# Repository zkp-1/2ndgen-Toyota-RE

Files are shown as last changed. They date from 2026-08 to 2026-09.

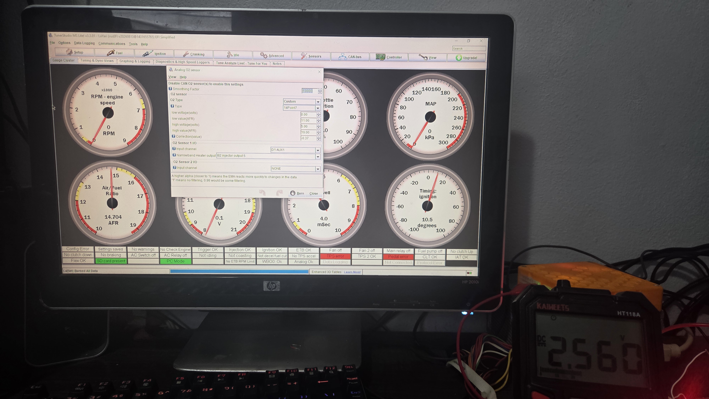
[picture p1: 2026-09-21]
AFR-Sensor/Testbench/20260920_163902.jpg

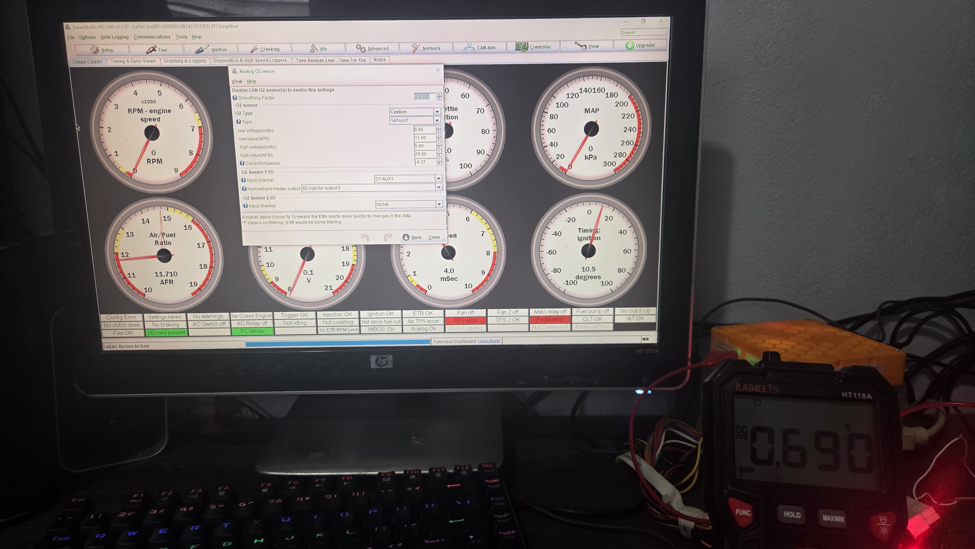
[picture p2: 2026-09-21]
AFR-Sensor/Testbench/20260920_163911.jpg

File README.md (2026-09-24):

# (1NZ-FE) Yaris Reverse Engineering
Reverse Engineering focused on the 1NZ-FE Platform for 2nd gen Yaris/Vitz.
My main focus is for this platform to be accesible in a plug and play fashion for the Rusefi Platform, although it could be done with other platforms if they can drive the ETB natively. I don't have a junker car or most parts to physically bench test, but I'll do my best to keep it updated as I make any progress on the project at all if any.

If you have anything that is useful to utilize the stock harness with a standalone ECU or pertinent info (like CANBUS chatter and labeled CANIDs) feel free to share it here, on any other repo, forum online or youtube video. Gatekeeping information just to possibly get a few bucks off from it rather than sharing it with everybody to access and analyze is honestly a waste of potential. These platforms are old, discontinued and not even popular at all. There honestly isn't a reason to share these things for the few people who like it other than abstaining from helping the platform stay alive.
# Useful links
- [Haltech 1NZ-FE Wiring Guide for their ECUs](https://support.haltech.com/portal/en/kb/articles/1nz-fe-engine). Has crank, cam, ETB and timing info.
# Disclaimers
This project is not affiliated with, endorsed by, or sponsored by Toyota. Toyota names, marks, vehicle model names, chassis codes, and engine codes are used only for identification and compatibility research.
# Continued
This project is licensed under the GNU General Public License v3.0 or later.

This project is intended for educational, research, motorsport, and off-road use only. Vehicle ECU, wiring, sensor, and engine-control modifications can cause engine damage, electrical damage, emissions noncompliance, unsafe vehicle behavior, personal injury, or death.

This project is not affiliated with, endorsed by, or sponsored by Toyota. Toyota names, marks, and vehicle identifiers are used only for compatibility and research identification.

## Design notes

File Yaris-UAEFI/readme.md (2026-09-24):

# Comments
Mostly untested. However tying MREL and IGSW do work (I have tried it). 

I've had mixed results with the ETB on the UAEFI. Sometimes it works, sometimes it doesn't. Am guessing it's a physical grounding issue on the harness adapter I have.

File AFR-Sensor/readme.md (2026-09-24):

# Recommendation: Use the 0-5V versions of the Projects

# Multisim folder

- Has the main 0-5V circuit. Mostly did the testing there. Voltage references are real and not ideal (Voltage dividers).
- It has a bunch of comments accounting for stuff like if there were a short circuit, component selection... etc.

# LTSpice folder

- Has both main and OEM style circuit. Does NOT have voltage dividers.
- Has the operation graphs (behavior at different currents).

# Testbench folder

- Custom iteration of the circuit (non-rail to rail op-amp with a pot voltage divider and an older design).
- Pertinent testing information.
- Power draw is <20mA using 12V and 5V. With a status led, it is <50mA.

# KiCAD
- Design block of the circuit.

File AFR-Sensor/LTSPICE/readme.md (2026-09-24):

For 3.3V circuit:

~4.50V: ~19AFR [2.5mA]

3.30V: 14.7AFR [0mA]

~2.35V: ~12AFR [-2mA]

(Using the Planar A/F Sensor Review data. The circuit isn't exactly 1:1 with the graph, since the graph isn't linear but somewhat exponential.)

For 2.5V circuit:

~5V: ~19AFR [0.8mA]

2.5V: 14.7AFR [0mA]

~0V: ~12AFR [-0.8mA]

(Note: Since the differential voltage changes here, the lean reading in reality might be less than 19AFR maybe).

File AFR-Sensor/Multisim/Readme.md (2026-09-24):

The multisim file has a lot of comments inside the design. I'll mention the important ones.
Op-amp: I utilzed the MCP6024 since it's a quad, rail-to-rail and can handle -40C thru 120C operation. If you change the op-amp for another one, make sure it is rail to rail, and that it has a good PSRR (power supply rejection ratio; which is how stable it'll behave if the power supply voltage varies) and CMRR (Common mode rejection ratio; which is external noise attenuation).
Shunt AND op-amp inverting and feedback resistance: Select resistors with low ppm (<100, less than <50 is even better). Power rating can be 1/8W or greater.
Emitter resistors:  Select 120ohm resistors of 1/2W capability for safety. It can handle 1/4W during a short circuit to ground, but it is slightly over 80% using 1/4W as a reference but less than 1/4W.
Capacitors: X7R should be good, with good voltage capacity (50V peak to start). Haven't investigated too much into it as of sept 23 2026.
Voltage dividers: They can be separated and each output buffered if desired.
--- If the circuit is to be tested physically ---
On the Shunt measurement rail, sink your desired current using I = Vrail/R (Sinking current means connecting a resistor to the rail, and the other terminal to ground). This simulates a shift to lean condition.
To simulate a rich condition shift, add any voltage (doesn't matter magnitude since the op-amp will force whatever the rail gets to Vrail) in series with the resistor, and this will inject/source current into the shunt, making the PNP sink the current. The equation remains: I = Vrail/R.
If using the 2.5V design, then Vrail = 2.5V. If using the Toyota style references, then Vrail = 3.3V.
Expected behavior:
Idle (no sourcing/sinking): V = Stoich (~2.5V default)
Fully lean (sinking 0.8mA): V = +5V
Fully rich (sourcing 0.8mA): V = 0V (may be millivolts, but it should be less than 500mV)
For more info or a schematic, lookup the testbench circuit I made alongside my results as a reference in the repo.

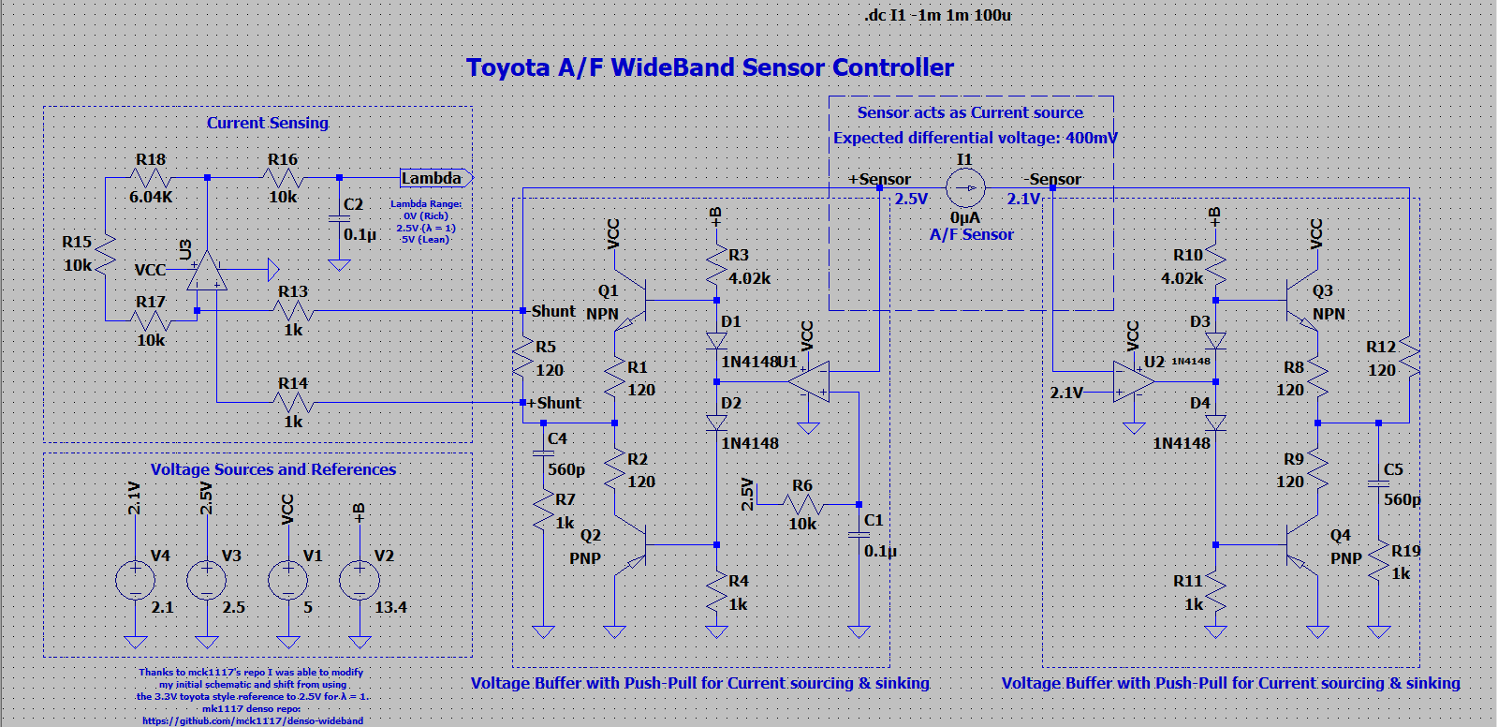
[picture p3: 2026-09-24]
AFR-Sensor/LTSPICE/Schematic.PNG

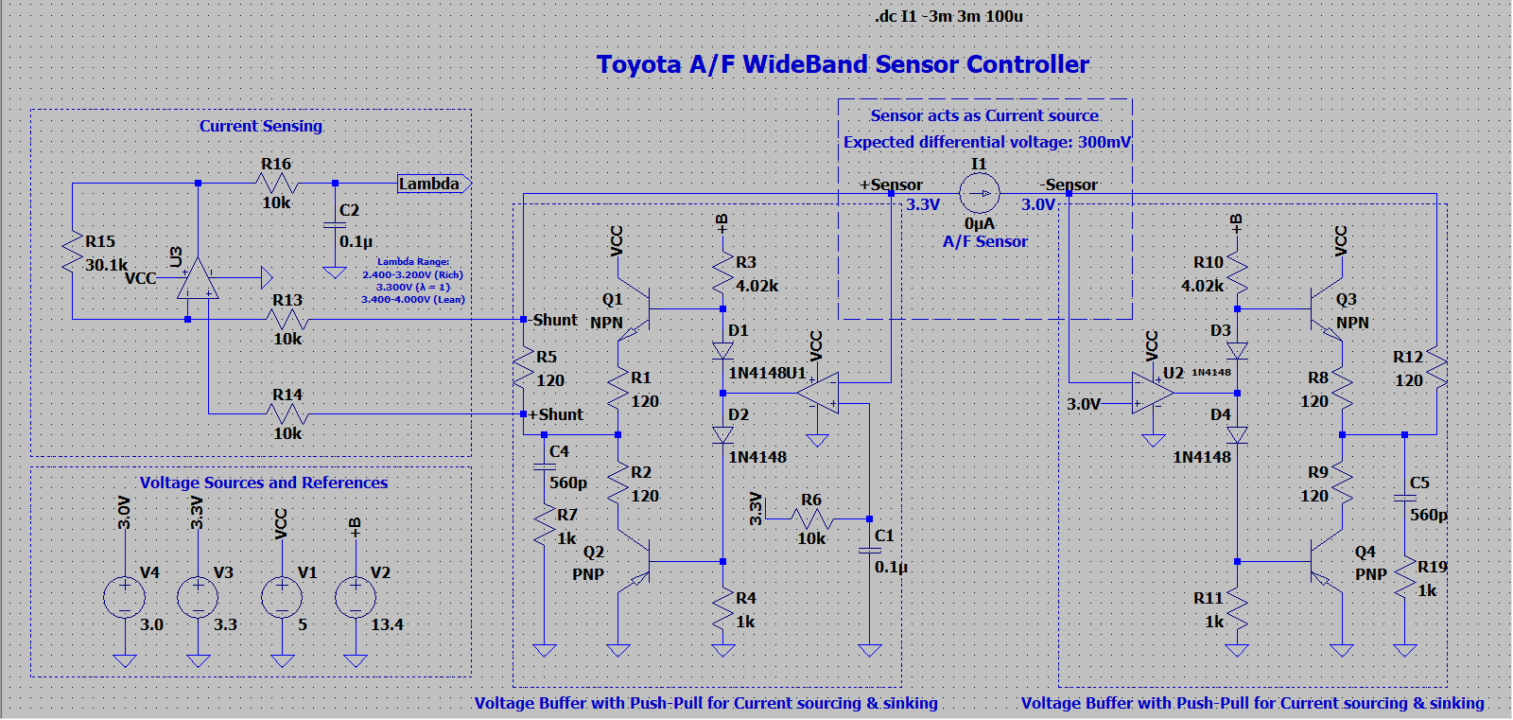
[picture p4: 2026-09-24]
AFR-Sensor/LTSPICE/Schematic_3.3V.PNG

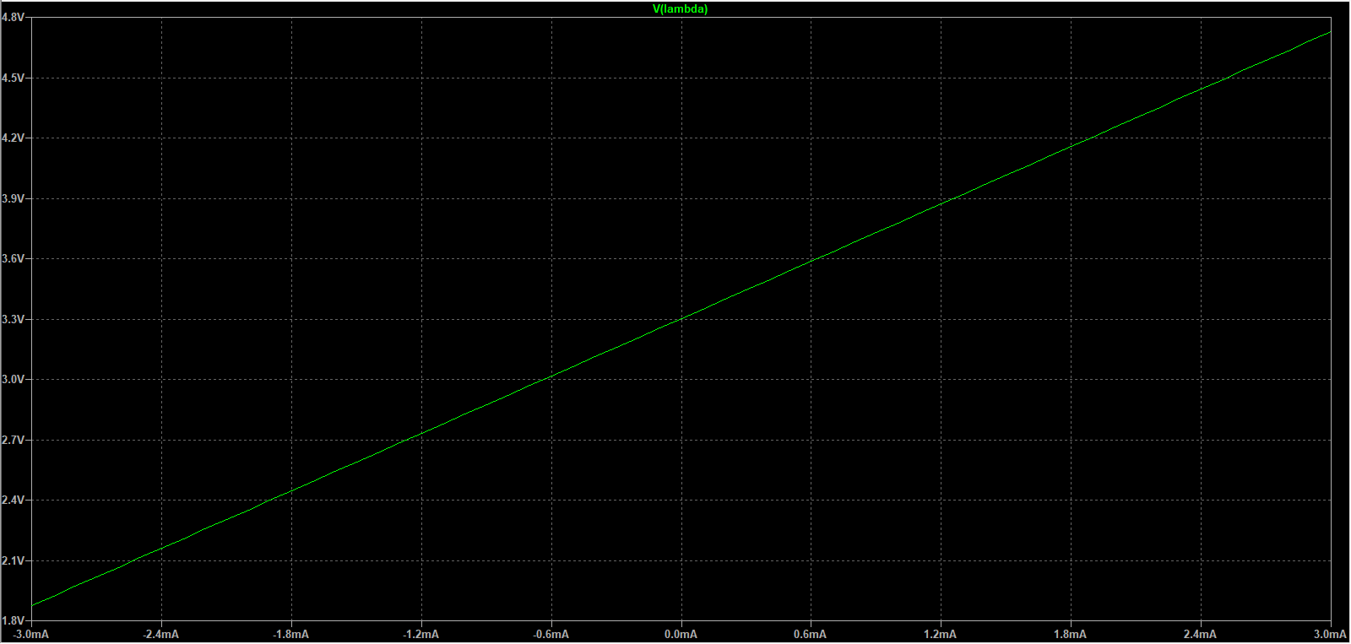
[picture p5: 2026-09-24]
AFR-Sensor/LTSPICE/Graph_3.3V.PNG

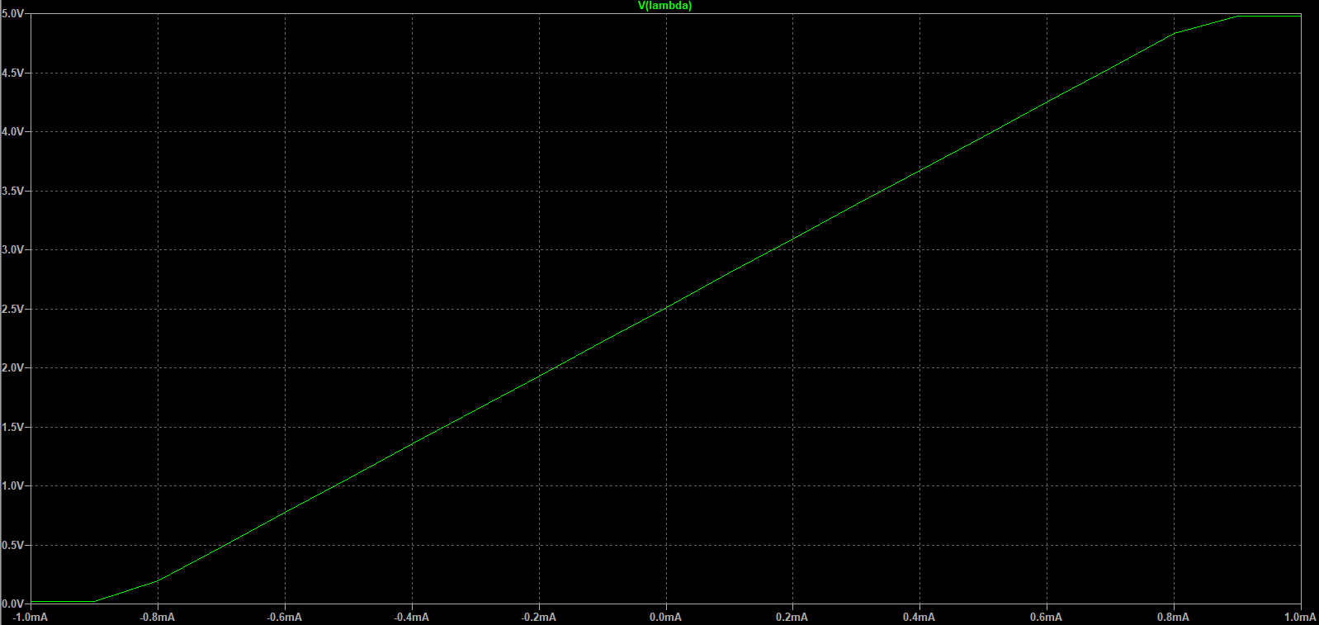
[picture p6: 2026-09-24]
AFR-Sensor/LTSPICE/Graph.PNG

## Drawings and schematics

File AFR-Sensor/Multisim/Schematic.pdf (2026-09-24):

# 13 ¹¹ 4

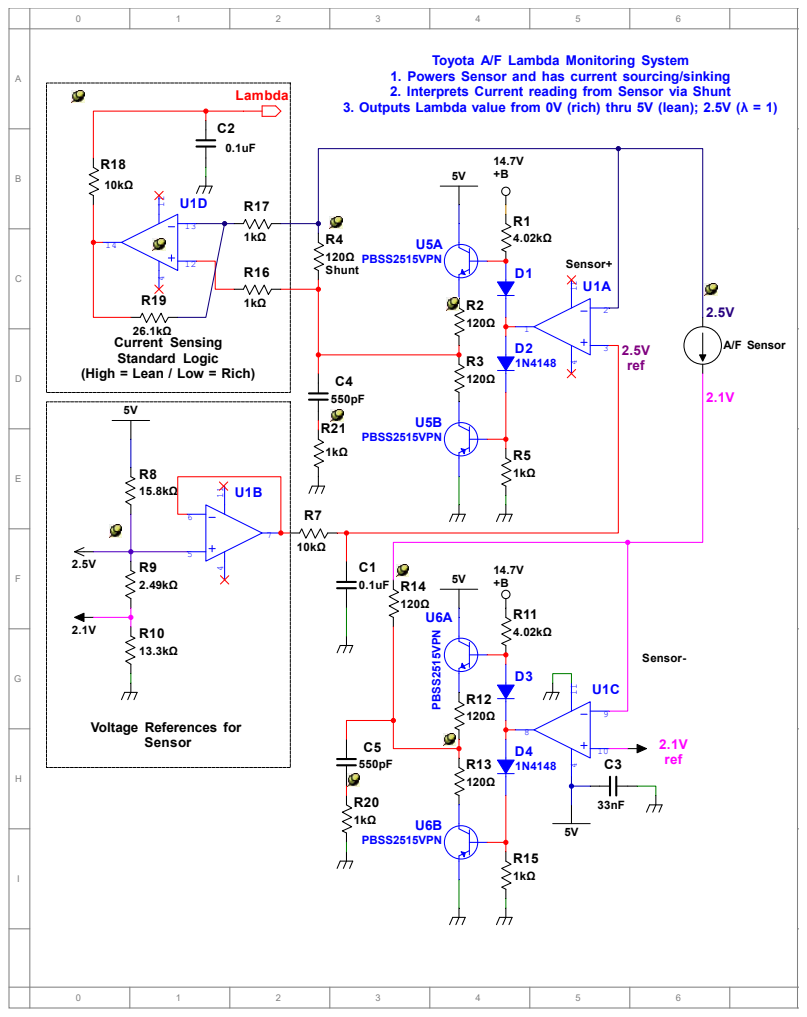
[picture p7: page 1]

Toyota A/F Lambda Monitoring System
1. Powers Sensor and has current sourcing/sinking
2. Interprets Current reading from Sensor via Shunt

3. Outputs Lambda value from 0V (rich) thru 5V (lean); 2.5V (λ = 1)

ABCDEFGHI

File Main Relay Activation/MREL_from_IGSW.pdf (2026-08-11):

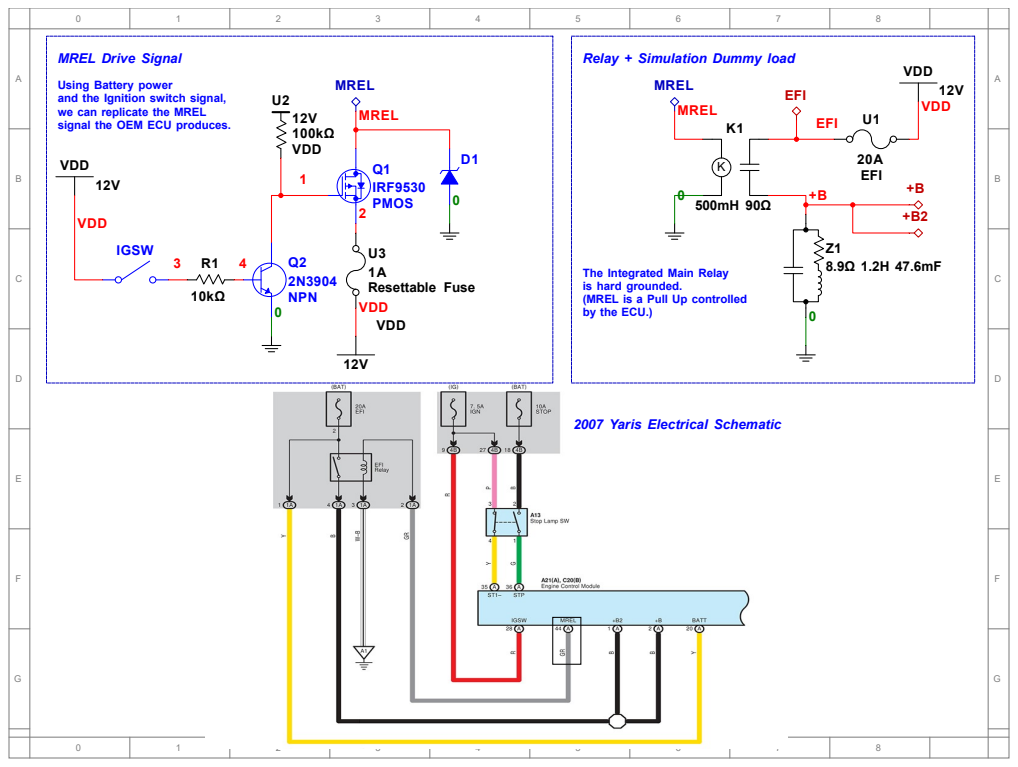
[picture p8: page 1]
Q1 IRF9530 PMOS; VDD; IGSW; 12V 100kΩ VDD; Q2 2N3904 NPN; MREL; MREL Drive Signal; Relay + Simulation Dummy load; 20A EFI; EFI; U3 1A Resettable Fuse

Using Battery power
and the Ignition switch signal,
we can replicate the MREL
signal the OEM ECU produces.

The Integrated Main Relay
is hard grounded.
(MREL is a Pull Up controlled
by the ECU.)

2007 Yaris Electrical Schematic

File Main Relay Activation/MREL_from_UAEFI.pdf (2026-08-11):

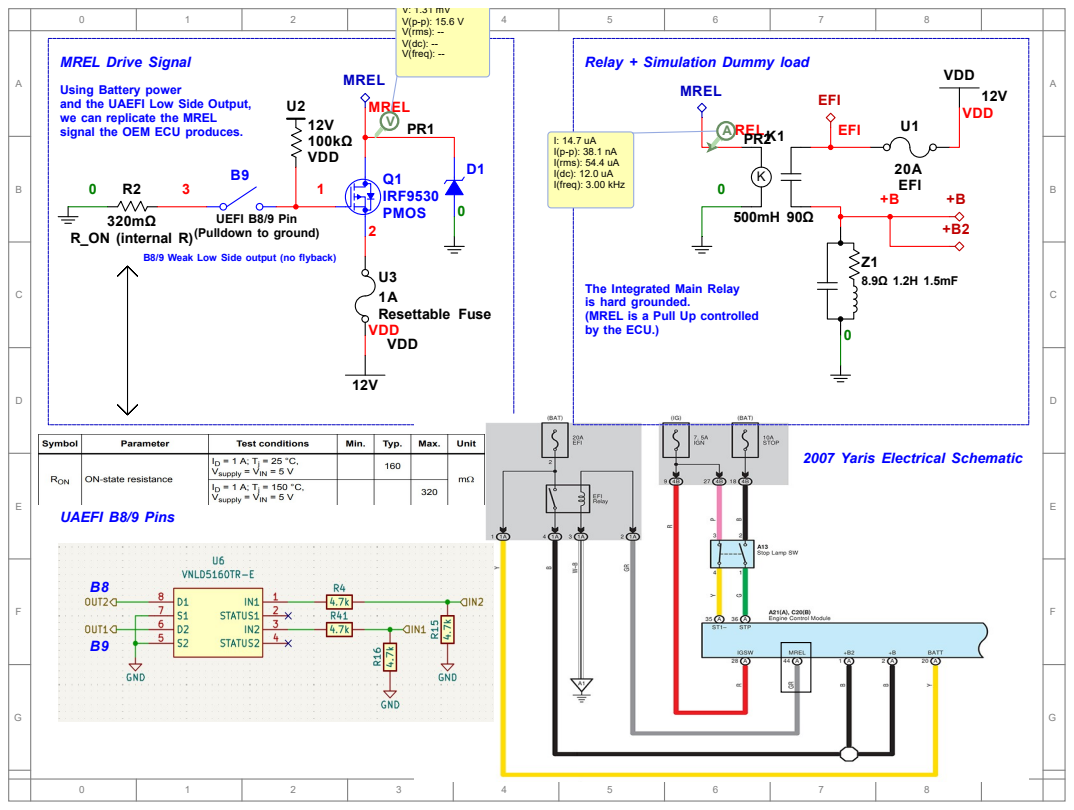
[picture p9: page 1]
Q1 IRF9530 PMOS; 12V 100kΩ VDD; MREL; VDD; MREL Drive Signal; Relay + Simulation Dummy load; 20A EFI; EFI; U3 1A Resettable Fuse VDD; UAEFI B8/9 Pins; 320mΩ R_ON (internal R); MREL PR1 V; V: 1.31 mV V(p-p): 15.6 V V(rms): -- V(dc): -- V(freq): --; I: 14.7 uA I(p-p): 38.1 nA I(rms): 54.4 uA I(dc): 12.0 uA I(freq): 3.00 kHz

Using Battery power
and the UAEFI Low Side Output,
we can replicate the MREL
signal the OEM ECU produces.

UEFI B8/9 Pin
(Pulldown to ground)

B8/9 Weak Low Side output (no flyback)

The Integrated Main Relay
is hard grounded.
(MREL is a Pull Up controlled
by the ECU.)

2007 Yaris Electrical Schematic

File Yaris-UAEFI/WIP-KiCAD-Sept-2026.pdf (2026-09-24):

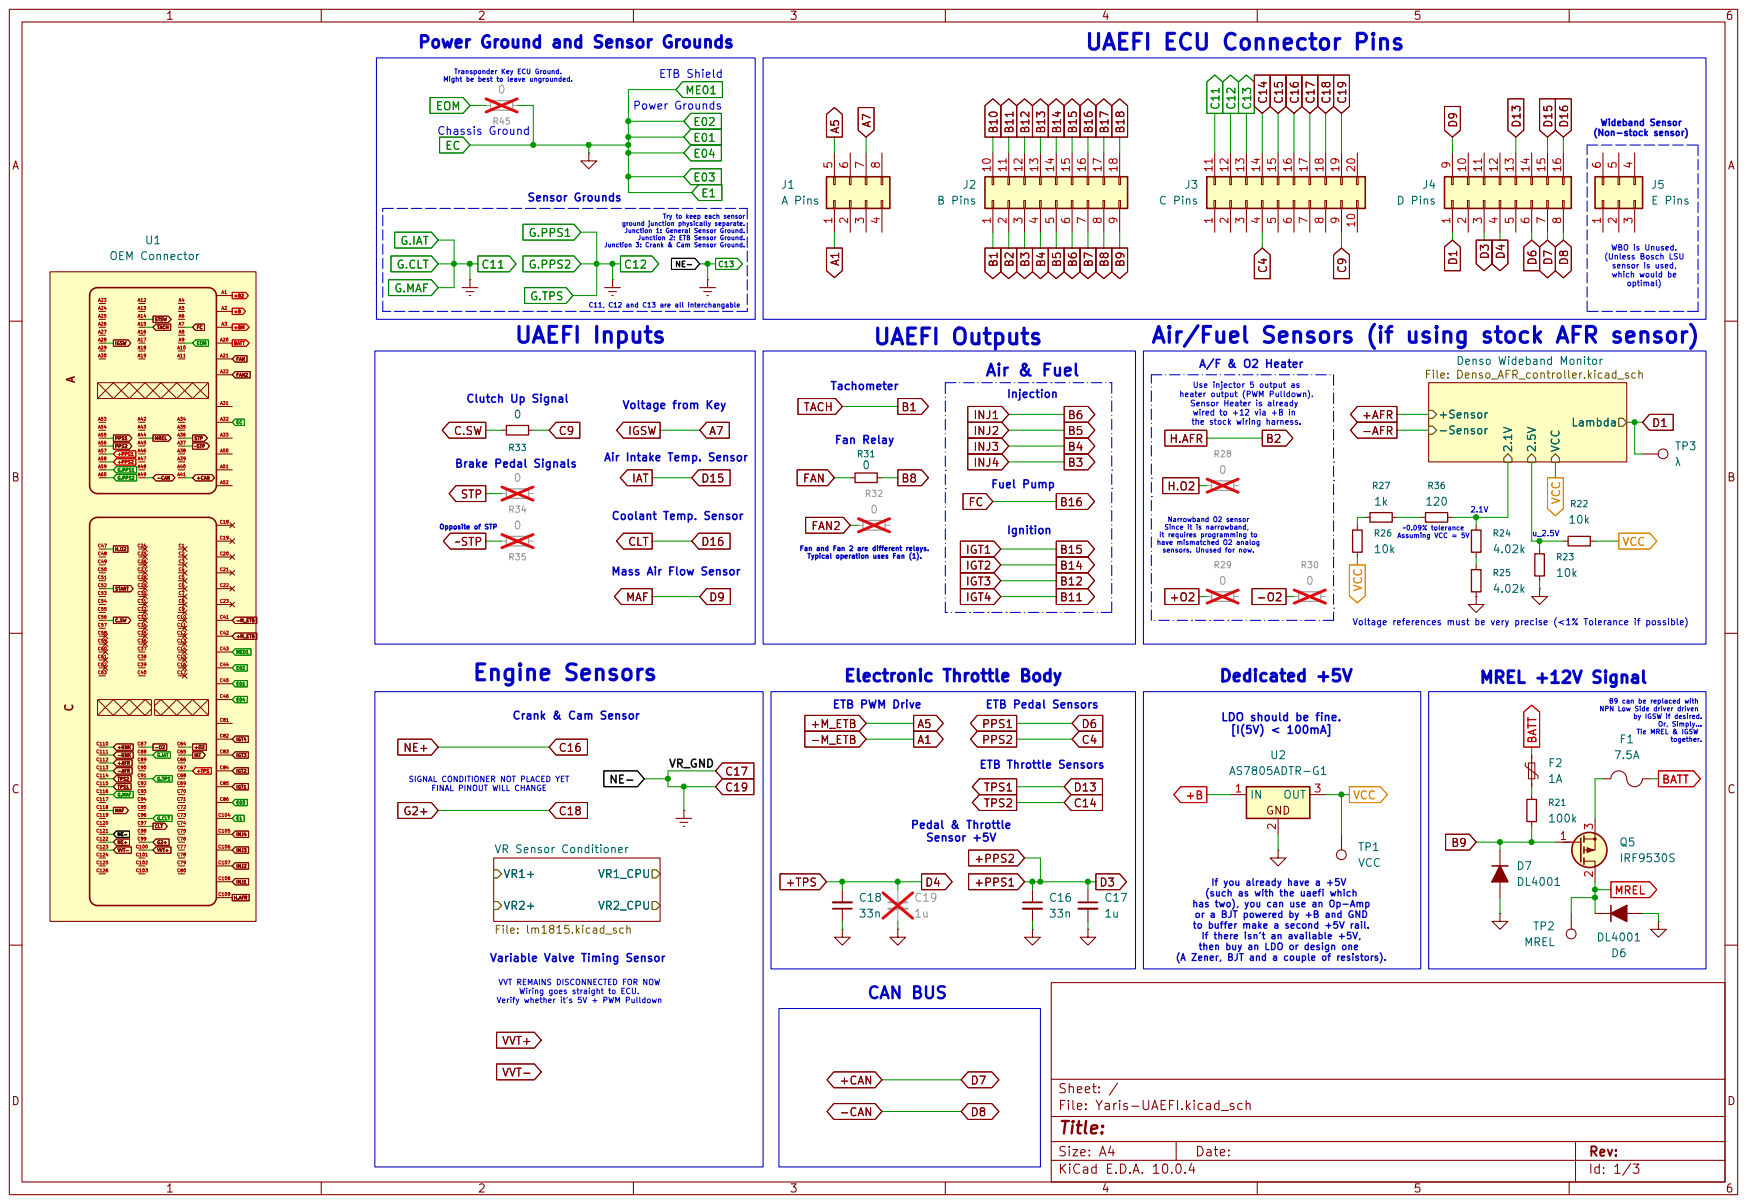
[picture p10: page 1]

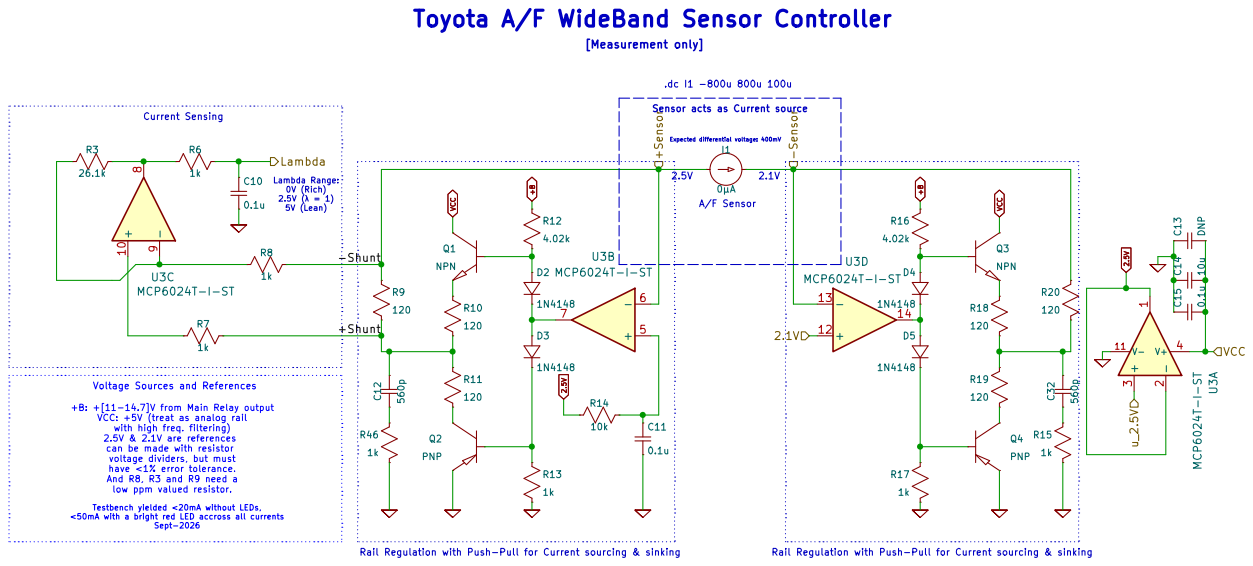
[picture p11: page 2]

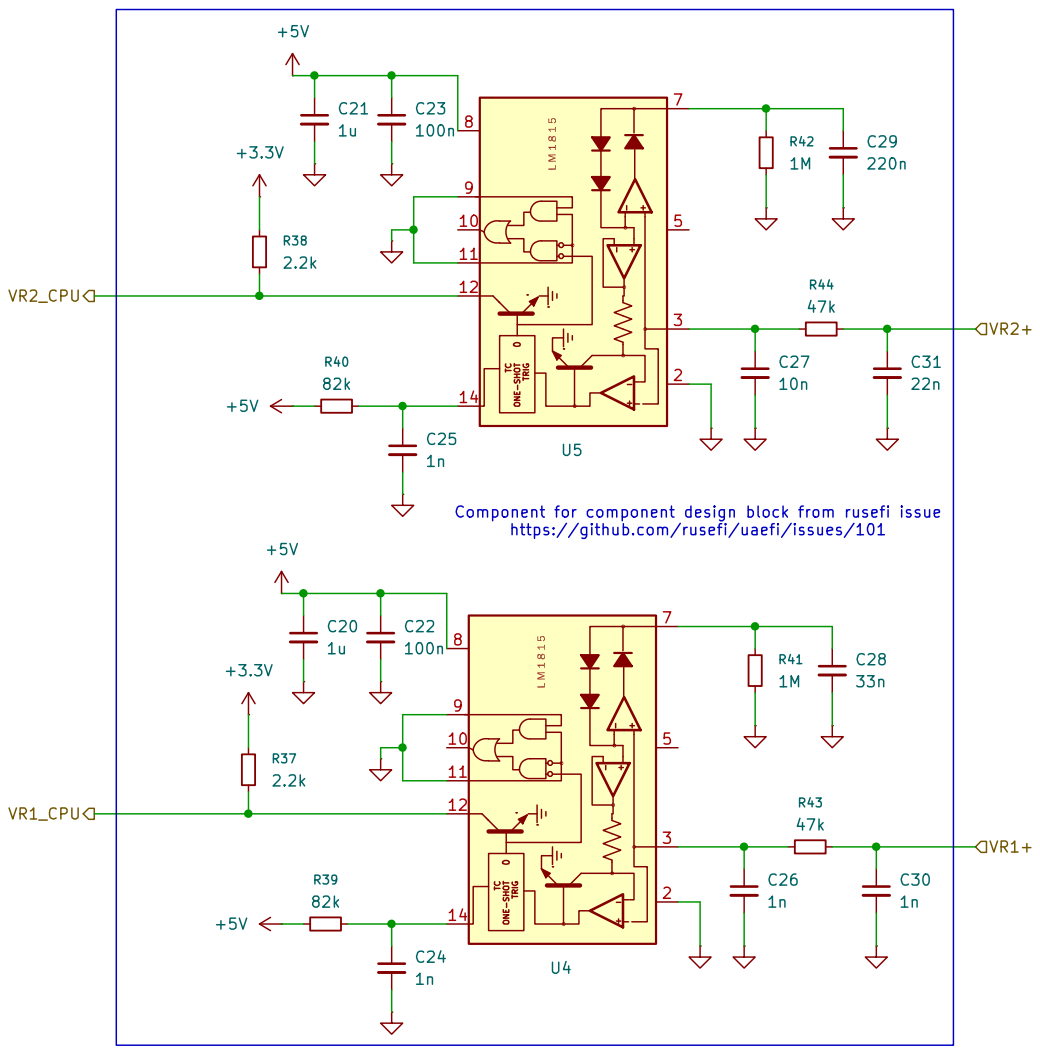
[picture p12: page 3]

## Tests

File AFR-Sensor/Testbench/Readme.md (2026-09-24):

The testbench setup used non-rail to rail Op-amps (LF353 and LM358D) and typical/generic BJTs (2N3904 and 2N3906).

The voltage supply was not ideal (VCC was less than 12V slightly, and 5V was slightly over). Since the op-amps weren't rail to rail, I powered the Op-amps dealing with the lambda output with VCC/2, to allow the voltage to swing near 5V.

V+ = 2.5V approx and V- = 2.1V approx. If you wish to use V+ = 3.300V and V- = 3.000V, then you'd need to change the gain of the Shunt resistor amplifier to account so it can respond to the 300mV differential voltage.

I'll attach an excerpt of my comments from the main multisim schematic.

--- Output voltage analysis ---

Vo = Rf/Ri(VShunt+ - VShunt-) + VShunt+
Vo = Rf/Ri(2.5V - VShunt-) + 2.5V
When I = 0A, VShunt- = VShunt+ = 2.5V, therefore:

Vo = 0 + 2.5V = 2.5V @ I = 0A

--- Gain analysis ---

The differential voltage depends on VShunt-. We can infer the value
from the expected current range: -800uA < 0 < 800uA.

|VShunt+-| = |I|R = 800μA * 120 = 96mV

At a max, Vo = 5V (Max lean condition).

5V = Rf/Ri(96mV) + 2.5V -> 2.5V/96mV = Rf/Ri -> Rf/Ri = 26.04

Since Ri = 1k, then Rf = 26.04k = 26.1k (≤ 1% tol)

For Vo = 0V (Max Rich condition):
0V = Rf/Ri(-96mV) + 2.5V -> -2.5V/-96mV = Rf/Ri -> Rf/Ri = 26.04
Notice the gain value stays the same, therefore it is no problem as long as the gain approximates 26.

Note*: If you wanted to use the stock differential voltage, then you'd need to have a gain that satisfies both the I = 2.5mA case and the I = -2mA case.

I verified the calculations needed, and you'd need a gain of roughly G = 3. (Consult LTSPICE 3.3V model)

So, it would be:

Rf = 30.1k and Ri = 10k. for V+ = 3.300V and V- = 3.000V

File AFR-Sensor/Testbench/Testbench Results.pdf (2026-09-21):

## Denso AFR Wideband Controller

Testing Conditions | Testing Parameters | Result | Expected Result | Notes
Verify voltage on +Sensor and -Sensor Rails (current source unconnected) | V+ = 2.5V V- = 2.1V | V+Sensor = 2.575V V-Sensor = 2.083V VCC = 11.89V +5V = 5.146V Vdiff = 492mV | V+Sensor ≅ 2.5V V-Sensor ≅ 2.1V | Differential Voltage Rails should be accurate (within <0.5%)
Verify op-amp offset (ground inputs and power with VCC = 5V and Ground) | |Voff | = ? V | |Voff| = 20.1mV | Depends on Op-amp used. MCP602x has |Voff | = 500 μV | Offset should be as small as possible.
Assembled circuit as seen in the schematic Compare results with simulation. | Typical Circuit Operation | I = 0A; λ = 2.560V I = 760μA; λ = 4.523V I = -759μA; λ = 0.690V (24mV) P = 10Ω P = 57.6μW | When I = -800μA, λ = 0V When I = 0A, λ = 2.5V When I = 800μA, λ = 5V | V P = R
Assembled circuit as seen in the schematic; RE = 1Ω Compare results with simulation and first tests. | RE Variation | I = ___; λ = ___ I = ___; λ = ___ I = ___; λ = ___ PRE = ___ | When I = -800μA, λ = 0V When I = 0A, λ = 2.5V When I = 800μA, λ = 5V | V P = R
Assembled circuit as seen in the schematic; RE = 0Ω Compare results with simulation and previous tests. | RE Removal | I = ___; λ = ___ I = ___; λ = ___ I = ___; λ = ___ PRE = ___ | When I = -800μA, λ = 0V When I = 0A, λ = 2.5V When I = 800μA, λ = 5V | V P = R

Additional Notes or Calculations:

Power Supply used is not great, and the chosen components aren’t rail to rail, even with the workarounds, it’s not perfect.
2.1V rail was adjusted with trim pot (R2 = pot) due to lack of resistors. Adjusted to 2.1V (a little higher to account for 2.578V voltage). Performance seemed alright, it calculated AFR just fine. Couldn’t be bothered to change replace RE with jumpers or resistor values. The power dissipated is very low during sink & sourcing (used highest Power value). I wouldn’t lower it since at a short, the current would be I =

= 250mA.

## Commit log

2026-08-10 AFR files 10/08/26
    Files for AFR Sensor monitor/controller design
2026-08-10 Add Main Relay Pull up driver Schematics
2026-08-11 Update files
    Changed relay model to 90Ohm. According to this issue (https://github.com/rusefi/uaefi/issues/100), its a 90 ohm relay.
    Fixed typo.
2026-09-24 Updated circuit
    Accounted for short to gnd and shorted rail cases and changed resistor values.
    Did a temp sweep, and it seems to work on cold and hot temps like as expected from the MCP6024.
    Removed cap between + and - Sensor rails, replaced with individual filtering on the push-pull output.
2026-09-24 Delete AFR-Sensor/Multisim/Graph.PNG
    Outdated
2026-09-24 LTSpice Update circuit
    Updated circuit from multisim testing.
    Updated 3.3V and adjusted gain to match 0-5V performance.
2026-09-24 Create readme.md
    ltspice 3.3V circuit and 2.5V circuit values
2026-09-24 Update readme.md
    value correction for 3.3V range
2026-09-24 AFR Sensor circuit Design Block upload
    kicad design block
    [Denso_AFR_controller.kicad_sch]
2026-09-24 UAEFI Schematic KiCAD Files
    Upload KiCAD files
    [Denso_AFR_controller.kicad_sch, Yaris-UAEFI.kicad_sch, lm1815.kicad_sch]
2026-09-24 Add Schematic PDF
2026-09-26 Fix LPF R value
    wrong LPF resistor on lambda output
    [Denso_AFR_controller.kicad_sch]
2026-10-11 Fix Transistor pinout
    Transistor pins Collector and Emitter were swapped in simulation but the testbench was correctly wired. Circuit still works but the transistor behaves active in reverse (slightly higher base current, which means higher power dissipation).
    Fixed LTSpice wiring.
2026-10-11 Fix transistor pinout
    Fixed Multisim wiring.
    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
2026-10-29 Signal Trace of AFR Sensor in a Denso ECU
    Added paper inspecting the AFR signal chain within a Denso ECU near the same timeframe as the 2nd gen 1NZ.
